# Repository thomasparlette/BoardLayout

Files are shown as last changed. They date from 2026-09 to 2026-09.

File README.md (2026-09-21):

# Grand Marquis 1997 MS3 replacement PCB — R10 eight-layer candidate

> **Engineering checkpoint — not released for fabrication or vehicle use.**

This repository contains the active R10 eight-layer KiCad candidate for a custom controller in a 1997 Mercury Grand Marquis EEC-V enclosure. The design is still `ROUTING_INCOMPLETE`.

## Current verified inventory

The read-only static audit of the native board reports:

- 246 footprints and 888 pads;
- 737 assigned pad/net pairs matching `source/input_netlist.xml`, excluding the intentionally off-board J121 entry;
- eight copper layers (`F.Cu`, `In1.Cu`–`In6.Cu`, `B.Cu`);
- 43,176 segments and 2,230 through vias;
- 102 zero-length segments;
- 207 exact duplicate segment geometries, comprising 208 extra records;
- 3,339 locked segments and 89 locked vias.

Run `py source/production_baseline_audit.py` to regenerate `production_review/BASELINE_AUDIT.md` and the machine-readable audit. This parser is a reproducible inventory tool; it does not replace KiCad DRC, ERC, zone refill, or visual review.

## Stale validation warning

`reports/Routing_validation.json` is behind the current board by 280 segments and four vias. `reports/After_routing_DRC.txt` is also a saved checkpoint, not a current native run. Its 24 unconnected-item findings and other category counts must be regenerated before routing work begins.

## Release blockers

- Native DRC and ERC must be rerun on the current files.
- Every true open, unintended dangling object, zero-length segment, duplicate segment, and unexplained zone island must be resolved without weakening rules.
- The 0.20 mm Default class conflicts with the 0.25 mm signal target in `REQUIREMENTS_CURRENT.md`.
- The eight-layer physical stackup and copper weights are not selected.
- Footprints, procurement BOM, functional pin mapping, current paths, via arrays, thermal interfaces, mechanical fit, and automotive protection remain incompletely qualified.
- Bench, transient, engine, and transmission validation have not been performed.

See `production_review/RELEASE_STATUS.md` and `production_review/KNOWN_HOLDS.md` for the controlling release posture.

## Primary files

- `GrandMarquis97_RevA.kicad_pro`, `.kicad_sch`, and `.kicad_pcb`: active native project.
- `GM97_Layout.pretty`, `GM97.kicad_sym`, and `models`: project libraries.
- `REQUIREMENTS_CURRENT.md`: current project requirements.
- `production_review`: regenerated audit evidence and release status.
- `reports`: current and historical engineering reports; check each report's date and provenance before relying on it.
- `source`: audit and historical routing scripts. Do not rerun historical routing automation wholesale against the active board.

No release Gerbers or drill package are provided.

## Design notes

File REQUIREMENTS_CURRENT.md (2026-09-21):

# 1997 Grand Marquis MS3 EEC-V Replacement Board — Current Requirements

## Vehicle and project objective

- Vehicle: 1997 Mercury Grand Marquis, 4.6 L SOHC 2-valve V8.
- Retain the factory EEC-V PCM enclosure, factory harness connector, mounting arrangement and original case cooling edges.
- Replace the factory PCB with a custom KiCad PCB that hosts the MS3 mainboard interface and an integrated MS3X-equivalent I/O implementation.
- Reuse the verified factory EEC-V connector pad numbering and the supplied Ford pin-reference material.
- Provide design files suitable for a mechanical prototype now and a later manufactured PCB after electrical validation.

## Engine control scope

- Use MegaSquirt 3 architecture with the existing MS3 card.
- Recreate the MS3X functions on the custom PCB.
- Use MapDaddy alone for MAP and barometric pressure.
- Use factory crank and cam signals with appropriate conditioning.
- Retain factory IAC: Ford F6AZ-9F715-EB, 1.0–1.2 A, commanded near 300 Hz.
- Use Bosch OE 62395 high-impedance injectors, 11–18 ohm.
- Initial ignition is dual waste-spark factory coil packs; COP/D585 coils are excluded from this revision.
- Coil primary design target: 4 A RMS per pack, 6 A nominal peak/dwell limit to be verified on the engine.
- Do not include EGR, EVAP, purge or other emissions controls.
- Replace factory narrowband O2 operation with external wideband controllers for Bosch LSU 4.2 or 4.9 sensors.
- Factory O2 heater circuits may provide the external controller supply; narrowband-related wiring may be used as a switched ground/enable only, subject to final schematic verification.

## Transmission and auxiliary control scope

- Retain the 4R70W automatic transmission.
- Use a MicroSquirt v3.0 mounted inside the vehicle for transmission control.
- Add a pass-through connector from the PCM shell to the custom PCB so the MicroSquirt can use the factory harness circuits.
- Pass-through opening available: approximately 0.75 in high by 1.5 in long. A flanged or PCB-edge solution is acceptable; removable crimp terminals are preferred.
- Transmission load assumptions: SSA/SSB 0.4–0.6 A; TCC 0.7–1.2 A; EPC 2.1–4.8 A pulsed. Verify against the actual transmission hardware before release.
- Fuel pump, fan and A/C outputs drive relay coils only. Other auxiliary loads assume 1–1.5 A maximum unless separately specified.

## Electrical requirements

- PCM receives 12 V through the original fused vehicle circuits; upstream ECM fuse is 30 A.
- The board provides internal power regulation.
- Support injector channels and the MS3X I/O assignments supplied by the user, including injector outputs, logic spark outputs, boost/idle mid-current outputs, flex-fuel, launch, table switch, datalog and auxiliary analog inputs.
- Use factory coil driver strategy initially. Requested ignition driver is FGD3245G2-F085C.
- Provide future compatibility for TO-220 and DPAK ignition-driver options, pending pinout, thermal and footprint verification.
- Separate power, digital, sensor and case-ground strategy must be retained and verified with the net-tie implementation.
- Preserve power-path target geometries: 4.0 mm shared VPWR/ACTUATOR_12/PGND target; 3.0 mm coil target; 2.0 mm injector target; 1.2 mm auxiliary/transmission target; 0.6 mm rail target; 0.25 mm signal target. These are design targets, not certified current ratings.

## Mechanical and layout requirements

- Board outline: 140.93 mm × 163.36 mm.
- Nominal board thickness: 1.60 mm.
- Use the supplied factory mounting-hole measurements and actual mounting-hole locations.
- J120, J130, J131 and J140 are located at the bottom/rear of the board.
- Rear cover clearance from the board: 6.35 mm (1/4 in). Components may be mounted on both sides; clearance must be checked.
- Place heat-producing FETs/driver hardware adjacent to the case cooling edges with a defined thermal interface before production.
- Current R10 routing candidate uses eight copper layers: F.Cu, In1–In6.Cu and B.Cu, with through vias only. The final copper weights and dielectric stackup remain to be selected with the fabricator.
- Current underside component moves: D26 (89,120), D27 (80,126), D28 (80,117), D30 (90,131), D33 (78,133), all coordinates in mm.

## Manufacturing and documentation requirements

- Prefer SMD components where feasible; use both sides of the PCB when needed.
- Use JLCPCB constraints for final fabrication rules and confirm the selected eight-layer stackup before release.
- Create/update the BOM with actual orderable Mouser parts and verified footprints.
- Provide KiCad project, schematic sheets, board, custom symbols/footprints/models, BOM, current-routing report, layout images and STL mechanical-fit files.
- Provide a board-only STL and a component-envelope STL for test printing.

## Mandatory completion gates before manufacturing or vehicle use

- Resolve every KiCad unconnected-items error and every clearance, hole-clearance, edge-clearance, courtyard and rule error without suppressing rules.
- Remove unintended track/via dangling stubs and re-run DRC.
- Run a fresh ERC after the schematic is finalized.
- Independently verify the Ford connector pin map and every MS3/MS3X/MicroSquirt connection against authoritative documents and the actual hardware.
- Select and verify every BOM item, especially Q13–Q16 ignition driver footprints/pinouts, pass-through connector, fusing/protection, high-current parts and thermal hardware.
- Select final stackup/copper weights, then verify ampacity, via current sharing, neckdowns and heat dissipation for coils, injectors, IAC, EPC and other loads.
- Complete bench testing with JimStim, dummy loads and the actual MS3/MicroSquirt hardware, followed by automotive transient and engine/transmission validation.
- Confirm the printed mechanical fit in the factory PCM case, including connector engagement, shell pass-through, daughtercard height, MapDaddy/hose clearance, solder/lead protrusion and thermal clips/insulators.

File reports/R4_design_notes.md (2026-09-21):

# Grand Marquis 1997 - R4 engineering review

**NOT FOR FABRICATION, ASSEMBLY OR VEHICLE POWER.** This package contains actual corrected KiCad sources and a routing experiment. It is not a completed or current-qualified ECU. Read the generated reports before use. No Gerbers are supplied.

## Changes

- J101 now follows MS3 JP2 as shown in MS3XV30 Hardware 1.5 pages 205 and 206. In particular Spark A is pin 12, 5 V is pin 31, ground is pins 28/30/32, and 12 V is pins 33/34. The complete reviewed mapping is in reports/JP2_verified_mapping.json.
- Existing MapDaddy alone supplies MAP and barometric pressure. J150 is a four-wire adapter, **not** a native sensor footprint: 1 MAP signal, 2 signal ground, 3 regulated sensor 5 V, 4 barometric signal. Barometric conditioning reaches J100 pin 29 (JS5/AD6). J131 pin 2 is disconnected so an external source cannot drive this dedicated input. Confirm the actual module calibration and wire identities before connecting it.
- Schematic connection geometry aligned to 1.27 mm. Explicit source declarations added for externally supplied/return and derived rails. These flags describe intent; they do not supply power.
- All previous copper removed before synchronization to avoid retaining wrong-header connections. Forty-three small analog components moved to B.Cu. Underside clearance is unmeasured.
- J120/J130/J131/J140 retain the R3 rear-edge positions. Board outline and seven mounting locations retain R3 geometry and its unverified assumptions.
- Factory IAC retained with PWM low-side control. Factory wasted spark uses four power stages; no COP, EGR, purge or EVAP added. External wideband controllers and cabin MicroSquirt remain the intended architecture.

## Current targets are not validated ratings

Routing targets assume 70 micrometres copper and use 2.0 mm injector trunks, 1.2 mm auxiliary trunks, 3.0 mm ignition trunks and 4.0 mm shared power trunks. Signal traces use 0.25 mm. These dimensions alone DO NOT establish current capacity. The proposed copper assumption is not a released stackup.

The user's MS3X table describes the commercial MS3X external DB37, not the internal JP2 connector and not a simultaneous load rating. This PCB uses the Ford connector. Power returns, pad escapes, barrel plating, parallel-via transitions, voltage drop and total load still require assessment. The routing experiment can contain single-via transitions and incomplete paths; it is not suitable for high-current testing.

VND5N07TR-E has a typical 5 A current limit. That is not a guaranteed continuous 5 A channel rating. At 0.2 ohm, 5 A implies 5 W conduction loss per driver before temperature effects; eight such channels cannot be assumed thermally acceptable. No heatsink contact or copper area is qualified by these files.

MK-CoilDrvr is the proposed DIYAutoTune sourcing exception for Q13-Q16. Its exact supplied transistor and physical pinout must be checked against the existing provisional TO-220 footprints. Do not assume BIP373 protection or dwell limits carry over to the replacement device. Ignition primary peak current is separate from the table's 30 mA logic-output rating.

## Validation and remaining work

See reports/Schematic_checks.json and reports/Routing_validation.json. Native KiCad netlist export and PCB DRC were available. Native ERC was not run: this KiCad 7 CLI does not expose ERC. Run Inspect > Electrical Rules Checker in KiCad on the ROOT schematic; keep checks enabled. The custom grid/netlist checks are not equivalent to ERC.

Parts_list.md / reports/Parts_list.json enumerate all schematic components. **This is not an order-ready Mouser BOM.** Unselected components, exact land-pattern compatibility, fuse/PTC coordination, LM2937 load/ESR stability, automotive transients, driver thermal design and the transmission pass-through connector remain holds. No substitute component selection is implied by a generic value.

Further release requirements: finish missing routes; resolve DRC findings; verify ERC; establish stackup and current/thermal budget; verify case fit including module heights, pads and insulators; identify MK-CoilDrvr device; qualify vehicle wiring; complete an actual BOM; bench-test with current-limited power and simulated loads before engine use. This package does not include a validated ECU calibration.

The source migration scripts are one-time transformations of the prior revision, not an idempotent build system. Do not rerun them on this output. route_input.dsn and route_final.ses describe only this routing trial. The native PCB is the review output.

## References

- https://www.msextra.com/doc/pdf/MS3XV30_Hardware-1.5.pdf
- https://www.st.com/resource/en/datasheet/vnd5n07-e.pdf
- https://diyautotune.com/products/mapdaddy4
- https://diyautotune.com/products/mk-coildrvr
- https://www.ti.com/lit/gpn/LM2937

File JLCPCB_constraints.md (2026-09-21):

# JLCPCB fabrication review - 14 September 2026

Manufacturer changed to JLCPCB at the user's request. Reference: https://jlcpcb.com/capabilities/pcb-capabilities

The published multilayer 2 oz track/space minimum is 0.15/0.15 mm. R6 default low-current signal routing uses 0.20/0.20 mm, with some existing 0.25 mm traces retained. Wider load and rail classes retain their targets. JLCPCB lists a 0.254 mm or greater PTH annular ring for 2 oz. The Q1/Q2 draft footprints have only 0.15 mm rings and therefore need revision before a 2 oz release. Increasing the pad diameter alone conflicts with their present pitch.

The page distinguishes via and component-hole rules. Existing vias are 0.8 mm diameter with 0.4 mm drills. The inner copper default is 0.5 oz; do not assume that selecting 2 oz outer copper makes the inner layers 2 oz. Explicit stackup selection and confirmation remain required.

The routing calculations currently assume 70 um copper. This is a proposed build assumption, not a released JLCPCB stackup. Do not order using defaults. Hole plating, copper tolerances, soldermask, legend and the final outline also need fabrication checks.

Factory mounting geometry is retained. JLCPCB manufacturability does not establish the electrical spacing needed around ignition switching nodes, temperature rise, automotive transient immunity, or component compatibility. Those remain separate engineering requirements.

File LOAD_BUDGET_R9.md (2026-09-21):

# R9 routing load basis — provisional

- Four wasted-spark primary channels. User target: 6 A peak operating current, to be measured on the bench. Earlier 4 A RMS applies per coil pack, not each primary. Keep 10 A transient routing allowance per primary until characterized. This PCB does not establish or enforce a 6 A current limit by itself.
- Bosch OE 62395 high-impedance injectors, 11–18 ohms. Published MS3X 5 A channel specification is a reference rating, not proof that the replacement copper or selected devices meet it.
- Factory F6AZ-9F715-EB IAC: 1.0–1.2 A, user-specified 300 Hz PWM.
- External MicroSquirt V3 controls 4R70W. SSA/SSB 0.4–0.6 A; TCC 0.7–1.2 A. EPC 2.1–4.8 A supplied as a resistance-derived range, not a verified RMS waveform. Pass-through contacts and shared return paths require combined-load qualification.
- Remaining unspecified outputs: 1.5 A maximum each. Fuel pump, fan and A/C outputs drive relay coils only.
- ECU input uses factory 30 A upstream fuse. This is not a rating for each PCB trace or a substitute for coordinated board protection.
- Wideband controllers have external power; old heater outputs switch relay/enable loads. MapDaddy supplies MAP and barometric signals.

Trace widths and via arrays are provisional. Final copper weights, temperature rise, duty cycles, driver losses, connector ratings and case thermal interfaces require review before manufacture. The six-layer option preserves the mechanical test-board dimensions and component placements; actual manufacturer stackup is not selected.

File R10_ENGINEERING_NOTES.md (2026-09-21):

# R10 eight-layer routing candidate

Routing is in progress. The latest native result is reports/Routing_validation.json; this document does not declare completion or manufacturing release.

The candidate retains the 140.93 × 163.36 mm outline, mounting-hole coordinates and nominal 1.6 mm board thickness. The following diodes moved to the underside: D26 (89,120), D27 (80,126), D28 (80,117), D30 (90,131), and D33 (78,133), coordinates in millimetres. Other placements are unchanged from R9. Copper layers are F.Cu, In1–In6.Cu and B.Cu. The two added internal layers carry PGND and DGND pours as well as routed traces. Through vias only.

Power routing preserves the unqualified targets in reports/Routing_targets.json. The VPWR branch serving only F1 pin 1 uses a 1.0 mm trunk and 0.6 mm neck; the schematic specifies F1 as 1 A, with its actual part unselected. The ACTUATOR_12 branch serving D33 pin 1 uses the 1.2 mm EPC branch target. Shared VPWR and ACTUATOR_12 trunks remain 4.0 mm targets. Connector fanouts use parallel 0.6 mm necks on three layers and via arrays where space permits. None of these geometries establishes a current rating.

The source-netlist comparison verifies 737 pad/net assignments. This is consistency with the existing design, not an independent verification against Ford and MS3 hardware documentation.

## Release holds

- 216 of 240 parts-list entries remain UNSELECTED; component selection is incomplete.
- Q13–Q16 ignition footprints/pinouts remain on hold. The requested TO-220/DPAK alternatives are not qualified.
- The eight-layer copper weights and dielectric stackup require selection. The 70 µm assumption used for earlier width targets is not a confirmed manufacturing stackup.
- Neckdowns, via arrays, current sharing, coil dwell and thermal interfaces require electrical/thermal validation. A 6 A peak target is not hardware current regulation.
- No fresh schematic ERC is available from this runtime. Historical ERC is not a current pass.
- No bench, dummy-load, automotive-transient or engine/transmission validation has been performed.

## Mechanical fit files

The R10 STL files contain the board and available component body envelopes. The maximum modeled underside depth is 2.22 mm, within the user-specified 6.35 mm cover gap. They exclude solder and leads, the complete MS3 daughtercard, MapDaddy assembly and hoses, cable mating/latch envelopes, Ford connector body/bent-pin envelope, thermal clips and insulating pads. They are fit aids, not a complete assembly-clearance approval.

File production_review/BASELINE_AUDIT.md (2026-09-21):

# R10 static baseline audit

This report inventories the current working-tree native files without modifying the board. The preserved baseline is commit `b5af19f6b018b43a92e55f4675a8856e3b85c9b5`. This audit supplements, but does not replace, native KiCad DRC/ERC. KiCad was not available in the audit environment, so the checked-in DRC remains stale and release-blocking.

## Native-file inventory

- Board format version: `20221018`
- Board thickness: 1.60 mm
- Copper layers: F.Cu, In1.Cu, In2.Cu, In3.Cu, In4.Cu, In5.Cu, In6.Cu, B.Cu
- Embedded physical stackup: **no**
- Footprints / pads / named nets: 246 / 888 / 189
- Segments / vias / zones: 43176 / 2230 / 17
- Locked segments / vias: 3339 / 89
- Zero-length segments: 102
- Exact duplicate segment groups / extra records: 207 / 208
- Exact duplicate via groups / extra records: 0 / 0
- Stored-netlist comparison: 737 assigned pairs, MATCH

## Stale checked-in evidence

`reports/Routing_validation.json` understates the native board by **280 segments** and **4 vias**. The saved DRC was created on 2026-09-14 22:43:03 and was not rerun for this audit.

Saved DRC categories: `{"lib_footprint_mismatch": 199, "silk_edge_clearance": 2, "track_dangling": 199, "unconnected_items": 24, "via_dangling": 15}`

## Rule concerns

- Project minimum track width: 0.0 mm
- Project minimum clearance: 0.0 mm
- Globally ignored categories: footprint_type_mismatch, missing_courtyard, npth_inside_courtyard, pth_inside_courtyard
- DRC exclusions: 0
- The Default class remains 0.20 mm and there is no assigned 0.25 mm Signal class.

## Release disposition

`ROUTING_INCOMPLETE`

Do not modify routing or release fabrication outputs from this static audit. A fresh native DRC and ERC, zone refill, visual review, and all documented electrical/mechanical qualification gates remain required.

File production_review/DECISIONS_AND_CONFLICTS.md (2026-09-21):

# R10 decisions and conflicts

## Baseline preservation

The repository's initial commit, `b5af19f6b018b43a92e55f4675a8856e3b85c9b5`, is the immutable supplied baseline. `baseline/SHA256SUMS.txt` hashes every tracked baseline file. A second in-repository copy of the complete project was intentionally not added because Git already preserves the byte-identical baseline and duplicating the 26 MB board would increase review and repository cost without adding recoverability.

## Stale report conflict

The native board text controls object inventory over `reports/Routing_validation.json`. The board contains 43,176 segments and 2,230 vias; the report contains 42,896 and 2,226. The report is therefore historical until regenerated by native KiCad.

## Signal-width conflict

`REQUIREMENTS_CURRENT.md` and `reports/Routing_targets.json` specify a 0.25 mm signal target. The project Default net class remains 0.20 mm and has no dedicated Signal-class assignment. The 0.25 mm requirement controls unless an engineering decision explicitly changes it. No mass width change is authorized before native DRC and route-by-route review.

## Static versus native validation

The standard-library audit is accepted only for file inventory, exact-geometry checks, saved-report comparison, and stored-netlist mapping. Native KiCad remains controlling for connectivity, zone fill, DRC, ERC, library comparison, and manufacturing plots.

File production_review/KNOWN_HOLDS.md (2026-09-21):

# Known R10 holds

| Hold | Why it matters | Evidence required to close | Blocks |
|---|---|---|---|
| `NATIVE_DRC_HOLD` | Saved counts do not describe the current board. | Fresh native zone refill and DRC with disposition of every finding. | Routing completion and all release states above it |
| `ERC_NOT_RUN` | Logical and power-pin errors may remain in the current schematic hierarchy. | Fresh native ERC and reviewed disposition. | Prototype fabrication |
| `SIGNAL_WIDTH_CONFLICT` | The Default class is 0.20 mm while current requirements specify 0.25 mm signals. | Enforceable class assignment or an approved, documented engineering decision with exceptions. | CAD review |
| `STACKUP_HOLD` | Copper thickness, dielectric geometry, via capability, and impedance/current assumptions are not fixed. | Fabricator-specific eight-layer stackup checked against the design. | Prototype fabrication |
| `PIN_MAPPING_HOLD` | Stored-netlist agreement is not independent functional verification. | Authoritative Ford/MS3/MS3X/MicroSquirt mapping with reviewer sign-off. | Prototype fabrication |
| `IGNITION_DRIVER_HOLD` | Q13–Q16 device, pinout, tab, drive, clamp, package, and case interface are not fully qualified. | Authoritative part data, footprint comparison, electrical review, and thermal/mechanical definition. | Prototype fabrication and vehicle use |
| `BOM_HOLD` | Most exact orderable components and alternates remain unselected. | Buildable, lifecycle-checked BOM with verified footprints. | Prototype fabrication |
| `POWER_THERMAL_HOLD` | Trace targets alone do not establish ampacity or safe temperatures. | End-to-end path, via-sharing, transient, and thermal analyses using the selected stackup and real loads. | Prototype fabrication |
| `MECHANICAL_HOLD` | Existing models omit critical bodies, leads, connectors, hoses, daughtercard, and thermal hardware. | Complete envelope model, test print, and actual enclosure fit check. | Prototype fabrication |
| `PHYSICAL_TEST_HOLD` | No prototype, dummy-load, transient, thermal, or vehicle evidence is archived. | Controlled test results and corrective-action closure. | Production release and vehicle validation |

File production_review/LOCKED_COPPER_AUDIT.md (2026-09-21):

# Locked copper audit summary

The native board contains **3339 locked segments** and **89 locked vias**. `LOCKED_COPPER_AUDIT.csv` groups them by net and layer/span. This is an inventory only: route purpose and justification still require engineering review before any lock is removed.

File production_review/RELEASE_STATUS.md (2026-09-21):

# R10 release status

## Current state

`ROUTING_INCOMPLETE`

The current static baseline confirms that the saved validation reports are stale and that copper cleanup and true electrical connections remain unresolved. No fabrication package is authorized.

## Evidence available

- Native-board static inventory in `BASELINE_AUDIT.md` and `BASELINE_AUDIT.json`.
- 737 assigned PCB pad/net pairs match the stored source netlist, excluding J121.
- Checked-in saved DRC from 2026-09-14, retained only as a checkpoint.
- Existing mechanical envelope models retained as fit aids, not physical qualification.

## Evidence still required

- Fresh native KiCad board load, zone refill, DRC, and schematic ERC.
- Reviewed routing repairs and copper cleanup with before/after evidence.
- Independent Ford/MS3/MS3X/MicroSquirt functional mapping.
- Selected and verified footprints, BOM, stackup, copper weights, current paths, vias, and thermal interfaces.
- Complete mechanical fit evidence and prototype fabrication outputs.
- Prototype assembly, bench, automotive-transient, thermal, and vehicle testing as applicable to each higher release state.

The state must not advance until the applicable evidence exists in the repository and has been reviewed.

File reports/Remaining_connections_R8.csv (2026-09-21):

finding | x1_mm | y1_mm | item1 | x2_mm | y2_mm | item2
1 | 53.2000 | 65.7000 | Via [ACTUATOR_12] on F.Cu - B.Cu | 30.4000 | 46.9000 | Track [ACTUATOR_12] on In2.Cu, length 0.4243 mm
2 | 36.2000 | 35.9000 | Track [ACTUATOR_12] on F.Cu, length 0.0566 mm | 82.1700 | 27.9480 | Track [ACTUATOR_12] on F.Cu, length 0.0566 mm
3 | 90.5650 | 5.3000 | PTH pad 69 [AC_WOT_CUTOUT] of J1 | 47.8000 | 122.4000 | Track [AC_WOT_CUTOUT] on B.Cu, length 0.8485 mm
4 | 110.9000 | 138.3000 | Track [CKP_PLUS] on F.Cu, length 0.1000 mm | 104.1650 | 11.2000 | PTH pad 21 [CKP_PLUS] of J1
5 | 77.4000 | 21.7000 | Track [COIL_2] on B.Cu, length 0.8485 mm | 40.6000 | 44.0000 | Track [COIL_2] on In2.Cu, length 0.8485 mm
6 | 34.8750 | 150.7180 | PTH pad 2 [COIL_3] of Q15 | 121.1650 | 5.3000 | PTH pad 78 [COIL_3] of J1
7 | 102.2000 | 39.4000 | Track [COIL_4] on B.Cu, length 0.8485 mm | 109.7000 | 29.7000 | Track [COIL_4] on In2.Cu, length 1.8000 mm
8 | 106.7000 | 143.9000 | Track [DGND] on B.Cu, length 0.2000 mm | 107.6000 | 143.0000 | Track [DGND] on In1.Cu, length 1.2728 mm
9 | 99.0650 | 8.2500 | PTH pad 45 [FAN_CONTROL] of J1 | 25.9500 | 110.6050 | Track [FAN_CONTROL] on F.Cu, length 3.0500 mm
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

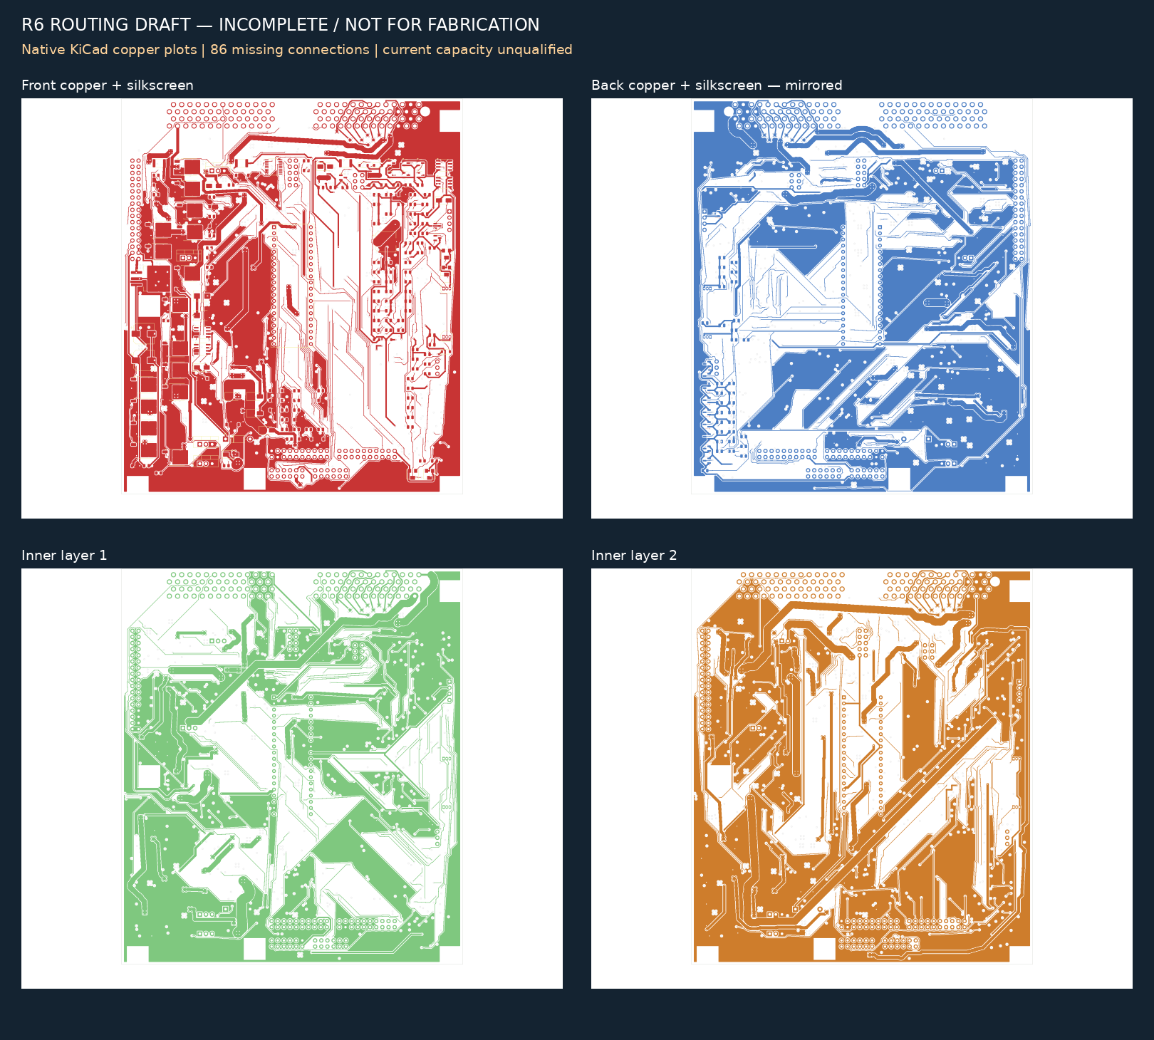
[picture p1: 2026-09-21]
mechanical/Layout_R6.png

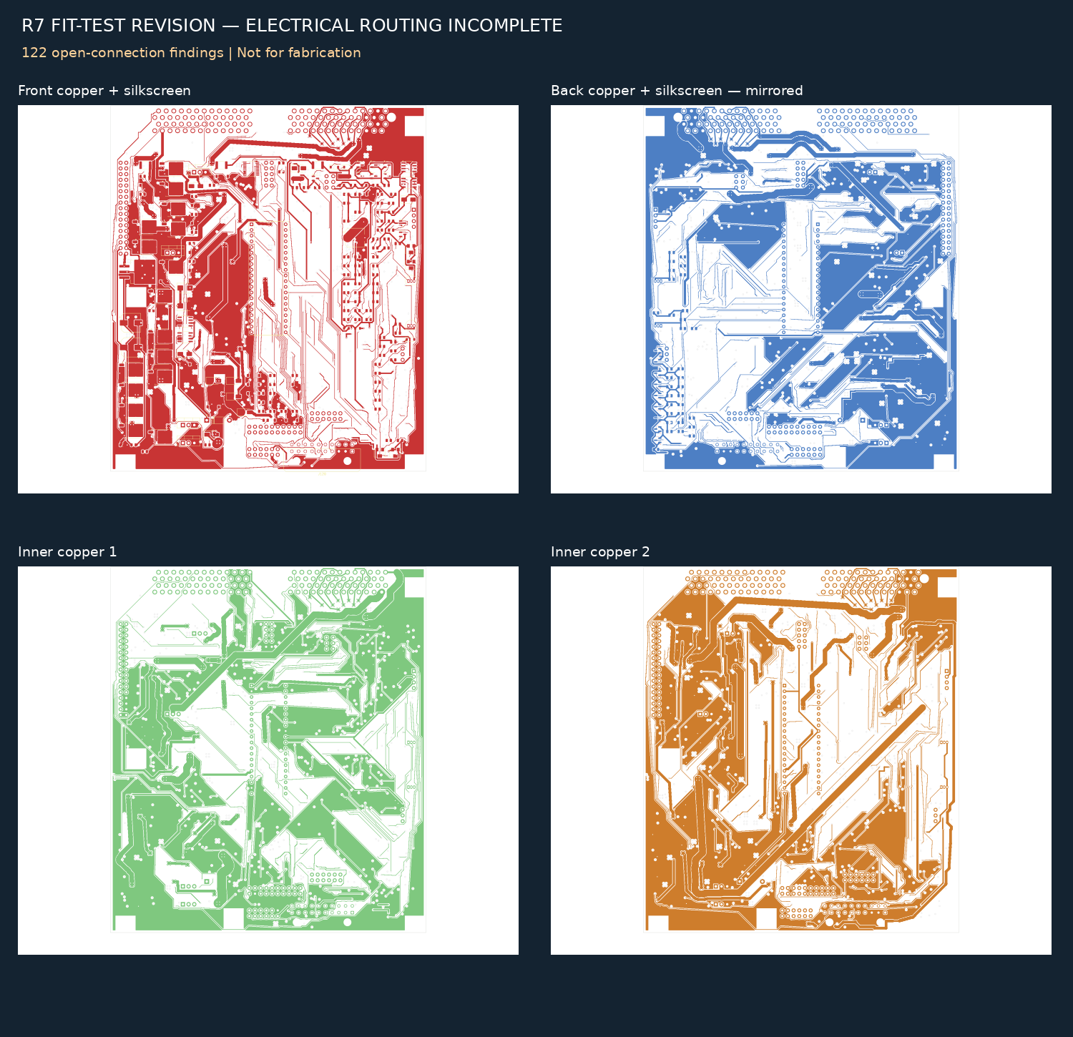
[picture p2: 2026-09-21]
mechanical/Layout_R7.png

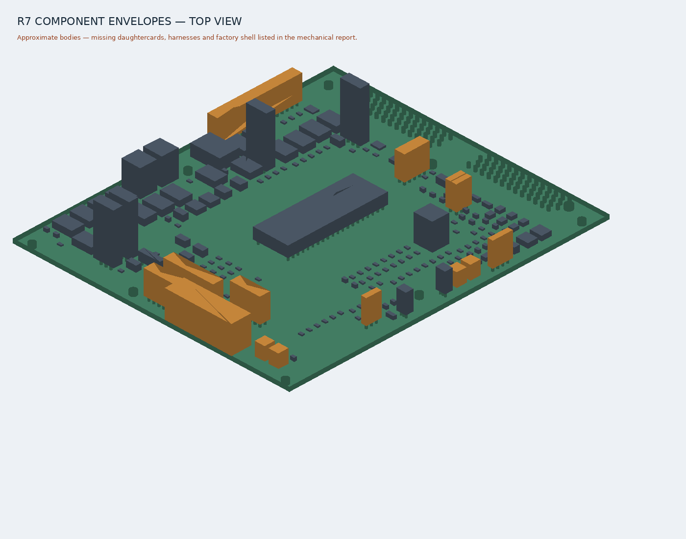
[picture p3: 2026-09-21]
mechanical/R7_Envelope_Preview.png

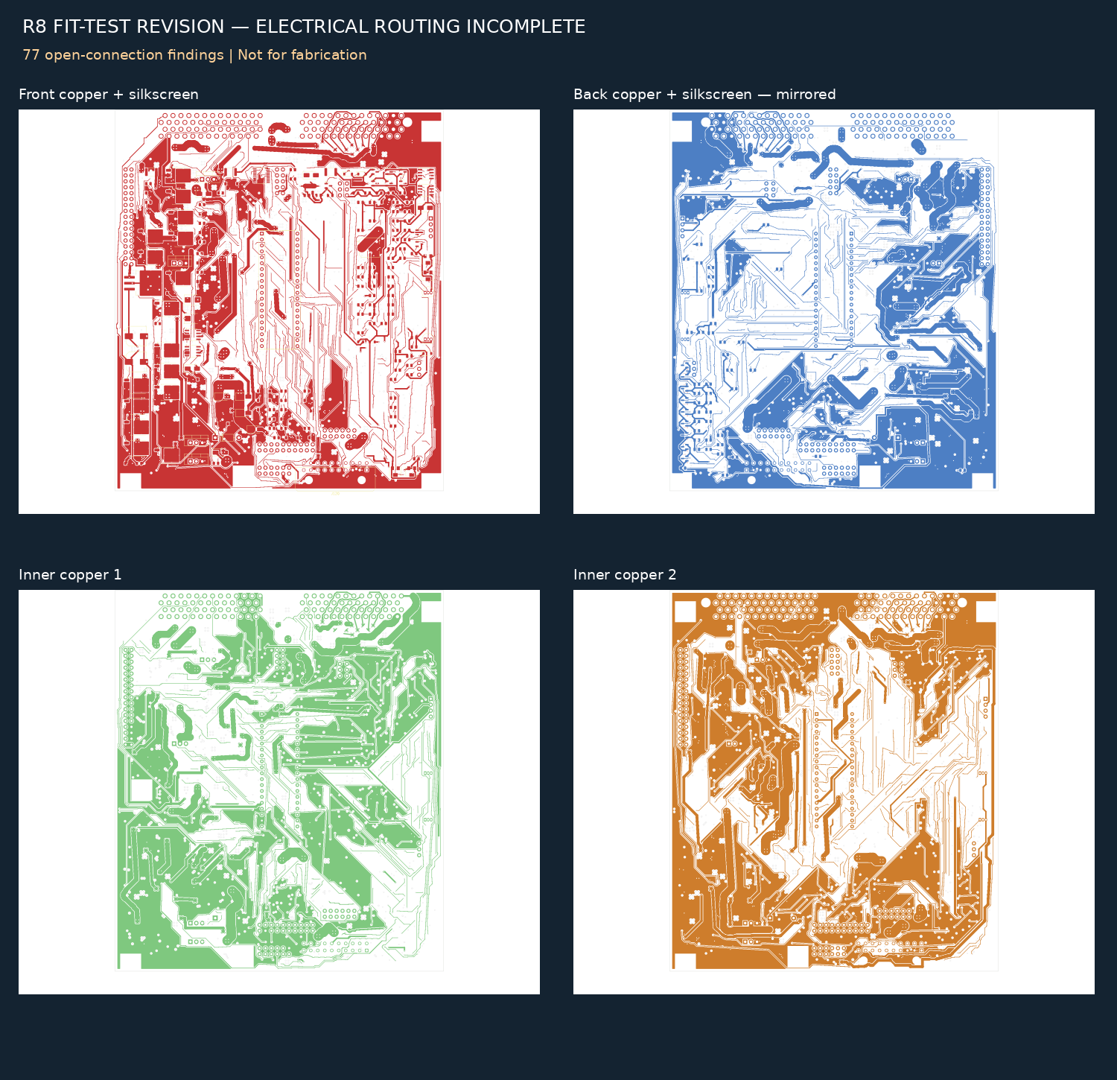
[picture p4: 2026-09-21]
mechanical/Layout_R8.png

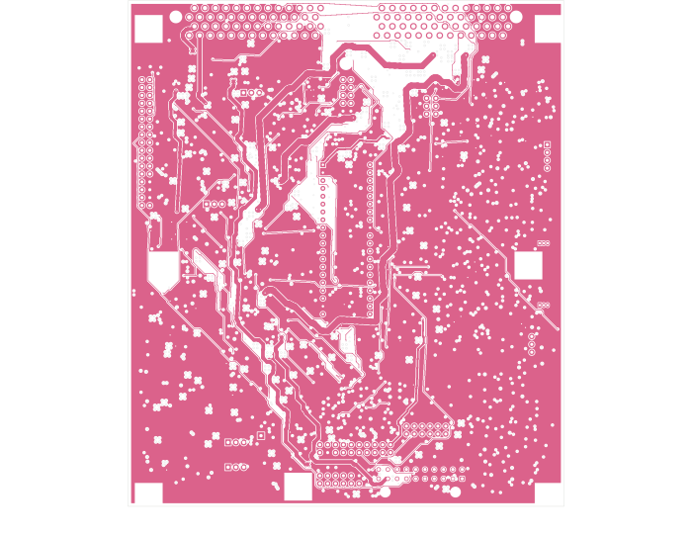
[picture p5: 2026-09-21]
mechanical/inner4.png

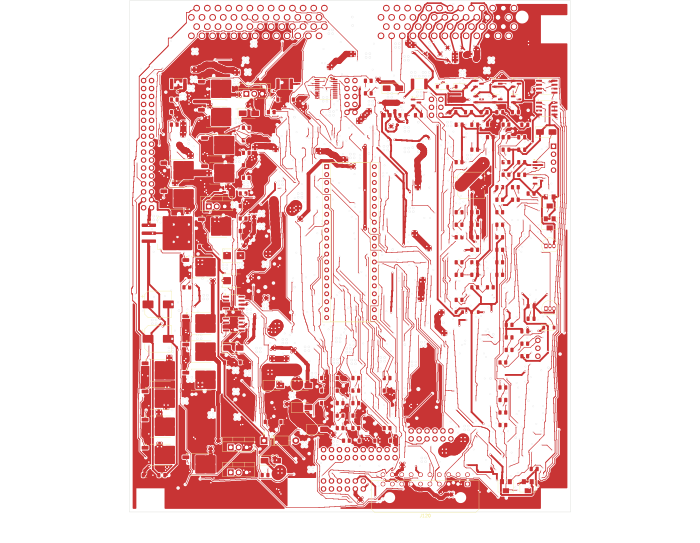
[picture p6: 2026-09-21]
mechanical/top.png

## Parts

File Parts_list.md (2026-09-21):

# R7 parts inventory — engineering review only

Not an order-ready BOM. All UNSELECTED entries and electrical/thermal limits remain open.

| Reference | Value | Part | Status |
|---|---|---|---|
| C1 | 33 uF / 50 V | UNSELECTED | HOLD: exact part and footprint qualification incomplete |
| C2 | 100 nF / 100 V | UNSELECTED | HOLD: exact part and footprint qualification incomplete |
| C3 | 33 uF / 10 V | UNSELECTED | HOLD: exact part and footprint qualification incomplete |
| C4 | 100 nF | UNSELECTED | HOLD: exact part and footprint qualification incomplete |
| C5 | 47 uF / 10 V | UNSELECTED | HOLD: exact part and footprint qualification incomplete |
| D1 | STPS3H100 | UNSELECTED | HOLD: exact part and footprint qualification incomplete |
| D2 | SMBJ18A TVS | UNSELECTED | HOLD: exact part and footprint qualification incomplete |
| D3 | 400V 1A SMA / MPN TBD | UNSELECTED | HOLD: exact part and footprint qualification incomplete |
| D4 | 1N4734A 5.6 V | UNSELECTED | HOLD: exact part and footprint qualification incomplete |
| F1 | 1 A SMD fuse / MPN TBD | UNSELECTED | HOLD: exact part and footprint qualification incomplete |
| F2 | PTC 0.5 A | UNSELECTED | HOLD: exact part and footprint qualification incomplete |
| U1 | LM2937ES-5.0 / SMD candidate | LM2937ES-5.0/NOPB | TI/Mouser candidate; load budget and output capacitor ESR/thermal HOLD |
| C6 | 4.7 uF | UNSELECTED | HOLD: exact part and footprint qualification incomplete |
| C7 | 100 nF | UNSELECTED | HOLD: exact part and footprint qualification incomplete |
| C8 | 4.7 uF | UNSELECTED | HOLD: exact part and footprint qualification incomplete |
| C9 | 100 nF | UNSELECTED | HOLD: exact part and footprint qualification incomplete |
| F3 | PTC 0.1 A | UNSELECTED | HOLD: exact part and footprint qualification incomplete |
| L1 | 1 uH | UNSELECTED | HOLD: exact part and footprint qualification incomplete |
| L2 | 1 uH | UNSELECTED | HOLD: exact part and footprint qualification incomplete |
| NT1 | NET_TIE | UNSELECTED | HOLD: exact part and footprint qualification incomplete |
| NT2 | NET_TIE | UNSELECTED | HOLD: exact part and footprint qualification incomplete |
| R1 | 0R DNP | UNSELECTED | HOLD: exact part and footprint qualification incomplete |
| R2 | 120R DNP | UNSELECTED | HOLD: exact part and footprint qualification incomplete |
| C10 | 100 nF | UNSELECTED | HOLD: exact part and footprint qualification incomplete |
| J100 | MS3_40_SOCKET | UNSELECTED | HOLD: exact part and footprint qualification incomplete |
| J101 | MS3_JP2_34 | UNSELECTED | HOLD: exact part and footprint qualification incomplete |
| J102 | MS3_INJ_10 | UNSELECTED | HOLD: exact part and footprint qualification incomplete |
| J1 | Ford104 | Salvaged original Ford 104-pin header | User accepted cavity mapping; contact ratings and mounting qualification HOLD |
| C11 | 1 uF | UNSELECTED | HOLD: exact part and footprint qualification incomplete |
| C12 | 1 nF | UNSELECTED | HOLD: exact part and footprint qualification incomplete |
| C13 | 1 uF | UNSELECTED | HOLD: exact part and footprint qualification incomplete |
| C14 | 1 nF | UNSELECTED | HOLD: exact part and footprint qualification incomplete |
| C15 | 220 nF | UNSELECTED | HOLD: exact part and footprint qualification incomplete |
| C16 | 1 nF | UNSELECTED | HOLD: exact part and footprint qualification incomplete |
| C17 | 220 nF | UNSELECTED | HOLD: exact part and footprint qualification incomplete |
| C18 | 1 nF | UNSELECTED | HOLD: exact part and footprint qualification incomplete |
| D5 | BAT54S | UNSELECTED | HOLD: exact part and footprint qualification incomplete |
| D6 | BAT54S | UNSELECTED | HOLD: exact part and footprint qualification incomplete |
| D7 | BAT54S | UNSELECTED | HOLD: exact part and footprint qualification incomplete |
| D8 | BAT54S | UNSELECTED | HOLD: exact part and footprint qualification incomplete |
| R3 | 2.2k | UNSELECTED | HOLD: exact part and footprint qualification incomplete |
| R4 | 2.49k 1% | UNSELECTED | HOLD: exact part and footprint qualification incomplete |
| R5 | 2.2k | UNSELECTED | HOLD: exact part and footprint qualification incomplete |
| R6 | 2.49k 1% | UNSELECTED | HOLD: exact part and footprint qualification incomplete |
| R7 | 1k | UNSELECTED | HOLD: exact part and footprint qualification incomplete |
| R8 | 1M | UNSELECTED | HOLD: exact part and footprint qualification incomplete |
| R9 | 1k | UNSELECTED | HOLD: exact part and footprint qualification incomplete |
| R10 | 1M | UNSELECTED | HOLD: exact part and footprint qualification incomplete |
| C19 | 220 nF | UNSELECTED | HOLD: exact part and footprint qualification incomplete |
| C20 | 1 nF | UNSELECTED | HOLD: exact part and footprint qualification incomplete |
| C21 | 220 nF | UNSELECTED | HOLD: exact part and footprint qualification incomplete |
| C22 | 1 nF | UNSELECTED | HOLD: exact part and footprint qualification incomplete |
| C23 | 220 nF | UNSELECTED | HOLD: exact part and footprint qualification incomplete |
| C24 | 1 nF | UNSELECTED | HOLD: exact part and footprint qualification incomplete |
| C25 | 220 nF | UNSELECTED | HOLD: exact part and footprint qualification incomplete |
| C26 | 1 nF | UNSELECTED | HOLD: exact part and footprint qualification incomplete |
| D9 | BAT54S | UNSELECTED | HOLD: exact part and footprint qualification incomplete |
| D10 | BAT54S | UNSELECTED | HOLD: exact part and footprint qualification incomplete |
| D11 | BAT54S | UNSELECTED | HOLD: exact part and footprint qualification incomplete |
| D12 | BAT54S | UNSELECTED | HOLD: exact part and footprint qualification incomplete |
| R11 | 1k | UNSELECTED | HOLD: exact part and footprint qualification incomplete |
| R12 | 1M | UNSELECTED | HOLD: exact part and footprint qualification incomplete |
| R13 | 1k | UNSELECTED | HOLD: exact part and footprint qualification incomplete |
| R14 | 1M | UNSELECTED | HOLD: exact part and footprint qualification incomplete |
| R15 | 1k | UNSELECTED | HOLD: exact part and footprint qualification incomplete |
| R16 | 1M | UNSELECTED | HOLD: exact part and footprint qualification incomplete |
| R17 | 1k | UNSELECTED | HOLD: exact part and footprint qualification incomplete |
| R18 | 1M | UNSELECTED | HOLD: exact part and footprint qualification incomplete |
| C27 | 220 nF | UNSELECTED | HOLD: exact part and footprint qualification incomplete |
| C28 | 100 nF | UNSELECTED | HOLD: exact part and footprint qualification incomplete |
| C29 | 100 nF | UNSELECTED | HOLD: exact part and footprint qualification incomplete |
| C30 | 220 nF | UNSELECTED | HOLD: exact part and footprint qualification incomplete |
| D13 | BAT54S | UNSELECTED | HOLD: exact part and footprint qualification incomplete |
| D14 | BAT54S | UNSELECTED | HOLD: exact part and footprint qualification incomplete |
| J150 | MapDaddy wired interface - user supplied module | 4-position wired adapter | Custom pin order; NOT a native MapDaddy package footprint; mount dimensions HOLD |
| R19 | 1k | UNSELECTED | HOLD: exact part and footprint qualification incomplete |
| R20 | 50k 1% | UNSELECTED | HOLD: exact part and footprint qualification incomplete |
| R21 | 10k 1% | UNSELECTED | HOLD: exact part and footprint qualification incomplete |
| R22 | 1k | UNSELECTED | HOLD: exact part and footprint qualification incomplete |
| R23 | 1M | UNSELECTED | HOLD: exact part and footprint qualification incomplete |
| C31 | 1 nF | UNSELECTED | HOLD: exact part and footprint qualification incomplete |
| C32 | 1 nF DNP | UNSELECTED | HOLD: exact part and footprint qualification incomplete |
| C33 | 100 nF | UNSELECTED | HOLD: exact part and footprint qualification incomplete |
| D15 | 1N4148W / candidate | UNSELECTED | HOLD: exact part and footprint qualification incomplete |
| Q1 | ZTX553 | UNSELECTED | HOLD: exact part and footprint qualification incomplete |
| Q2 | ZTX553 | UNSELECTED | HOLD: exact part and footprint qualification incomplete |
| R24 | 10k | UNSELECTED | HOLD: exact part and footprint qualification incomplete |
| R25 | 10k | UNSELECTED | HOLD: exact part and footprint qualification incomplete |
| R26 | 1M | UNSELECTED | HOLD: exact part and footprint qualification incomplete |
| R27 | 47k | UNSELECTED | HOLD: exact part and footprint qualification incomplete |
| R28 | 10k | UNSELECTED | HOLD: exact part and footprint qualification incomplete |
| R29 | 10k | UNSELECTED | HOLD: exact part and footprint qualification incomplete |
| R30 | 10k | UNSELECTED | HOLD: exact part and footprint qualification incomplete |
| R31 | 10k | UNSELECTED | HOLD: exact part and footprint qualification incomplete |
| R32 | 1k | UNSELECTED | HOLD: exact part and footprint qualification incomplete |
| R33 | 1k | UNSELECTED | HOLD: exact part and footprint qualification incomplete |
| R34 | 100k | UNSELECTED | HOLD: exact part and footprint qualification incomplete |
| R35 | 100k | UNSELECTED | HOLD: exact part and footprint qualification incomplete |
| R36 | 0R | UNSELECTED | HOLD: exact part and footprint qualification incomplete |
| U3 | MC34072 SOIC / candidate | UNSELECTED | HOLD: exact part and footprint qualification incomplete |
| C34 | 220 nF | UNSELECTED | HOLD: exact part and footprint qualification incomplete |
| C35 | 1 nF | UNSELECTED | HOLD: exact part and footprint qualification incomplete |
| D16 | 400V 1A SMA / MPN TBD | UNSELECTED | HOLD: exact part and footprint qualification incomplete |
| JP1 | CRANK POLARITY | UNSELECTED | HOLD: exact part and footprint qualification incomplete |
| R37 | 1k | UNSELECTED | HOLD: exact part and footprint qualification incomplete |
| R38 | 1k | UNSELECTED | HOLD: exact part and footprint qualification incomplete |
| R39 | 1M | UNSELECTED | HOLD: exact part and footprint qualification incomplete |
| R40 | 47k | UNSELECTED | HOLD: exact part and footprint qualification incomplete |
| R41 | 100k | UNSELECTED | HOLD: exact part and footprint qualification incomplete |
| R42 | 1k | UNSELECTED | HOLD: exact part and footprint qualification incomplete |
| R43 | 100k | UNSELECTED | HOLD: exact part and footprint qualification incomplete |
| R44 | 1k | UNSELECTED | HOLD: exact part and footprint qualification incomplete |
| R45 | 2.2k DNP | UNSELECTED | HOLD: exact part and footprint qualification incomplete |
| RV1 | 10k / CRANK ZERO | UNSELECTED | HOLD: exact part and footprint qualification incomplete |
| RV2 | 100k / CRANK HYST | UNSELECTED | HOLD: exact part and footprint qualification incomplete |
| C36 | 100 nF | UNSELECTED | HOLD: exact part and footprint qualification incomplete |
| Q3 | MMBT2907A | UNSELECTED | HOLD: exact part and footprint qualification incomplete |
| Q4 | MMBT2907A | UNSELECTED | HOLD: exact part and footprint qualification incomplete |
| RV3 | 10k / CAM ZERO | UNSELECTED | HOLD: exact part and footprint qualification incomplete |
| RV4 | 100k / CAM HYST | UNSELECTED | HOLD: exact part and footprint qualification incomplete |
| U4 | MCP6002-I/SN | UNSELECTED | HOLD: exact part and footprint qualification incomplete |
| Q5 | VND5N07 | VND5N07TR-E | ST datasheet/order code checked; thermal and current qualification HOLD |
| Q6 | VND5N07 | VND5N07TR-E | ST datasheet/order code checked; thermal and current qualification HOLD |
| Q7 | VND5N07 | VND5N07TR-E | ST datasheet/order code checked; thermal and current qualification HOLD |
| Q8 | VND5N07 | VND5N07TR-E | ST datasheet/order code checked; thermal and current qualification HOLD |
| R46 | 1k | UNSELECTED | HOLD: exact part and footprint qualification incomplete |
| R47 | 100k | UNSELECTED | HOLD: exact part and footprint qualification incomplete |
| R48 | 1k | UNSELECTED | HOLD: exact part and footprint qualification incomplete |
| R49 | 100k | UNSELECTED | HOLD: exact part and footprint qualification incomplete |
| R50 | 1k | UNSELECTED | HOLD: exact part and footprint qualification incomplete |
| R51 | 100k | UNSELECTED | HOLD: exact part and footprint qualification incomplete |
| R52 | 1k | UNSELECTED | HOLD: exact part and footprint qualification incomplete |
| R53 | 100k | UNSELECTED | HOLD: exact part and footprint qualification incomplete |
| Q9 | VND5N07 | VND5N07TR-E | ST datasheet/order code checked; thermal and current qualification HOLD |
| Q10 | VND5N07 | VND5N07TR-E | ST datasheet/order code checked; thermal and current qualification HOLD |
| Q11 | VND5N07 | VND5N07TR-E | ST datasheet/order code checked; thermal and current qualification HOLD |
| Q12 | VND5N07 | VND5N07TR-E | ST datasheet/order code checked; thermal and current qualification HOLD |
| R54 | 1k | UNSELECTED | HOLD: exact part and footprint qualification incomplete |
| R55 | 100k | UNSELECTED | HOLD: exact part and footprint qualification incomplete |
| R56 | 1k | UNSELECTED | HOLD: exact part and footprint qualification incomplete |
| R57 | 100k | UNSELECTED | HOLD: exact part and footprint qualification incomplete |
| R58 | 1k | UNSELECTED | HOLD: exact part and footprint qualification incomplete |
| R59 | 100k | UNSELECTED | HOLD: exact part and footprint qualification incomplete |
| R60 | 1k | UNSELECTED | HOLD: exact part and footprint qualification incomplete |
| R61 | 100k | UNSELECTED | HOLD: exact part and footprint qualification incomplete |
| C37 | 100 nF | UNSELECTED | HOLD: exact part and footprint qualification incomplete |
| R62 | 100k | UNSELECTED | HOLD: exact part and footprint qualification incomplete |
| R64 | 100k | UNSELECTED | HOLD: exact part and footprint qualification incomplete |
| R66 | 100k | UNSELECTED | HOLD: exact part and footprint qualification incomplete |
| R68 | 100k | UNSELECTED | HOLD: exact part and footprint qualification incomplete |
| U5 | SN74AHCT541PWR | UNSELECTED | HOLD: exact part and footprint qualification incomplete |
| C38 | 100 nF | UNSELECTED | HOLD: exact part and footprint qualification incomplete |
| C39 | 100 nF | UNSELECTED | HOLD: exact part and footprint qualification incomplete |
| Q13 | MK-CoilDrvr IGBT - PINOUT HOLD | MK-CoilDrvr | Kit specified; underlying IGBT MPN/pinout and case mounting HOLD |
| Q14 | MK-CoilDrvr IGBT - PINOUT HOLD | MK-CoilDrvr | Kit specified; underlying IGBT MPN/pinout and case mounting HOLD |
| Q15 | MK-CoilDrvr IGBT - PINOUT HOLD | MK-CoilDrvr | Kit specified; underlying IGBT MPN/pinout and case mounting HOLD |
| Q16 | MK-CoilDrvr IGBT - PINOUT HOLD | MK-CoilDrvr | Kit specified; underlying IGBT MPN/pinout and case mounting HOLD |
| R78 | 100k | UNSELECTED | HOLD: exact part and footprint qualification incomplete |
| R79 | 100k | UNSELECTED | HOLD: exact part and footprint qualification incomplete |
| R80 | 100k | UNSELECTED | HOLD: exact part and footprint qualification incomplete |
| R81 | 100k | UNSELECTED | HOLD: exact part and footprint qualification incomplete |
| R82 | 0R | UNSELECTED | HOLD: exact part and footprint qualification incomplete |
| R83 | 330R | UNSELECTED | HOLD: exact part and footprint qualification incomplete |
| R84 | 0R | UNSELECTED | HOLD: exact part and footprint qualification incomplete |
| R85 | 330R | UNSELECTED | HOLD: exact part and footprint qualification incomplete |
| R86 | 0R | UNSELECTED | HOLD: exact part and footprint qualification incomplete |
| R87 | 330R | UNSELECTED | HOLD: exact part and footprint qualification incomplete |
| R88 | 0R | UNSELECTED | HOLD: exact part and footprint qualification incomplete |
| R89 | 330R | UNSELECTED | HOLD: exact part and footprint qualification incomplete |
| U6 | TC4427A | UNSELECTED | HOLD: exact part and footprint qualification incomplete |
| U7 | TC4427A | UNSELECTED | HOLD: exact part and footprint qualification incomplete |
| D17 | 400V 1A SMA / MPN TBD | UNSELECTED | HOLD: exact part and footprint qualification incomplete |
| D18 | 400V 1A SMA / MPN TBD | UNSELECTED | HOLD: exact part and footprint qualification incomplete |
| D19 | 400V 1A SMA / MPN TBD | UNSELECTED | HOLD: exact part and footprint qualification incomplete |
| Q17 | VND5N07 | VND5N07TR-E | ST datasheet/order code checked; thermal and current qualification HOLD |
| Q18 | VND5N07 | VND5N07TR-E | ST datasheet/order code checked; thermal and current qualification HOLD |
| Q19 | VND5N07 | VND5N07TR-E | ST datasheet/order code checked; thermal and current qualification HOLD |
| R90 | 1k | UNSELECTED | HOLD: exact part and footprint qualification incomplete |
| R91 | 100k | UNSELECTED | HOLD: exact part and footprint qualification incomplete |
| R92 | 1k | UNSELECTED | HOLD: exact part and footprint qualification incomplete |
| R93 | 100k | UNSELECTED | HOLD: exact part and footprint qualification incomplete |
| R94 | 1k | UNSELECTED | HOLD: exact part and footprint qualification incomplete |
| R95 | 100k | UNSELECTED | HOLD: exact part and footprint qualification incomplete |
| D22 | 400V 1A SMA / MPN TBD | UNSELECTED | HOLD: exact part and footprint qualification incomplete |
| Q22 | VND5N07 | VND5N07TR-E | ST datasheet/order code checked; thermal and current qualification HOLD |
| R100 | 1k | UNSELECTED | HOLD: exact part and footprint qualification incomplete |
| R101 | 100k | UNSELECTED | HOLD: exact part and footprint qualification incomplete |
| D23 | 400V 1A SMA / MPN TBD | UNSELECTED | HOLD: exact part and footprint qualification incomplete |
| D24 | 400V 1A SMA / MPN TBD | UNSELECTED | HOLD: exact part and footprint qualification incomplete |
| Q23 | VND5N07 | VND5N07TR-E | ST datasheet/order code checked; thermal and current qualification HOLD |
| Q24 | VND5N07 | VND5N07TR-E | ST datasheet/order code checked; thermal and current qualification HOLD |
| R102 | 1k | UNSELECTED | HOLD: exact part and footprint qualification incomplete |
| R103 | 100k | UNSELECTED | HOLD: exact part and footprint qualification incomplete |
| R104 | 1k | UNSELECTED | HOLD: exact part and footprint qualification incomplete |
| R105 | 100k | UNSELECTED | HOLD: exact part and footprint qualification incomplete |
| Q26 | VND5N07 | VND5N07TR-E | ST datasheet/order code checked; thermal and current qualification HOLD |
| Q27 | VND5N07 | VND5N07TR-E | ST datasheet/order code checked; thermal and current qualification HOLD |
| R108 | 1k | UNSELECTED | HOLD: exact part and footprint qualification incomplete |
| R109 | 100k | UNSELECTED | HOLD: exact part and footprint qualification incomplete |
| R110 | 1k | UNSELECTED | HOLD: exact part and footprint qualification incomplete |
| R111 | 100k | UNSELECTED | HOLD: exact part and footprint qualification incomplete |
| C40 | 100 nF | UNSELECTED | HOLD: exact part and footprint qualification incomplete |
| C41 | 100 nF | UNSELECTED | HOLD: exact part and footprint qualification incomplete |
| C42 | 100 nF | UNSELECTED | HOLD: exact part and footprint qualification incomplete |
| C43 | 100 nF | UNSELECTED | HOLD: exact part and footprint qualification incomplete |
| D26 | BAT54S | UNSELECTED | HOLD: exact part and footprint qualification incomplete |
| D27 | BAT54S | UNSELECTED | HOLD: exact part and footprint qualification incomplete |
| D28 | BAT54S | UNSELECTED | HOLD: exact part and footprint qualification incomplete |
| D29 | BAT54S | UNSELECTED | HOLD: exact part and footprint qualification incomplete |
| R116 | 10k | UNSELECTED | HOLD: exact part and footprint qualification incomplete |
| R117 | 2.2k | UNSELECTED | HOLD: exact part and footprint qualification incomplete |
| R118 | 10k | UNSELECTED | HOLD: exact part and footprint qualification incomplete |
| R119 | 2.2k | UNSELECTED | HOLD: exact part and footprint qualification incomplete |
| R120 | 10k | UNSELECTED | HOLD: exact part and footprint qualification incomplete |
| R121 | 2.2k | UNSELECTED | HOLD: exact part and footprint qualification incomplete |
| R122 | 10k | UNSELECTED | HOLD: exact part and footprint qualification incomplete |
| R123 | 2.2k | UNSELECTED | HOLD: exact part and footprint qualification incomplete |
| D30 | 1N4148W / candidate | UNSELECTED | HOLD: exact part and footprint qualification incomplete |
| D31 | 1N4148W / candidate | UNSELECTED | HOLD: exact part and footprint qualification incomplete |
| D32 | BAT54S | UNSELECTED | HOLD: exact part and footprint qualification incomplete |
| Q30 | MMBT3904 | UNSELECTED | HOLD: exact part and footprint qualification incomplete |
| Q31 | MMBT3904 | UNSELECTED | HOLD: exact part and footprint qualification incomplete |
| R124 | 47k | UNSELECTED | HOLD: exact part and footprint qualification incomplete |
| R125 | 100k | UNSELECTED | HOLD: exact part and footprint qualification incomplete |
| R126 | 47k | UNSELECTED | HOLD: exact part and footprint qualification incomplete |
| R127 | 100k | UNSELECTED | HOLD: exact part and footprint qualification incomplete |
| R128 | 0R DNP | UNSELECTED | HOLD: exact part and footprint qualification incomplete |
| R129 | 2.2k | UNSELECTED | HOLD: exact part and footprint qualification incomplete |
| R130 | 10k | UNSELECTED | HOLD: exact part and footprint qualification incomplete |
| D33 | 400V 1A SMA / MPN TBD | UNSELECTED | HOLD: exact part and footprint qualification incomplete |
| J120 | Molex 43045-2000 | 43045-2000 | Selected header; verify mating assembly and simultaneous-current derating |
| JP2 | SPEED SOURCE + | UNSELECTED | HOLD: exact part and footprint qualification incomplete |
| JP3 | SPEED RETURN - | UNSELECTED | HOLD: exact part and footprint qualification incomplete |
| R131 | 2.2k DNP | UNSELECTED | HOLD: exact part and footprint qualification incomplete |
| R132 | 10k DNP | UNSELECTED | HOLD: exact part and footprint qualification incomplete |
| R133 | 2.49k DNP | UNSELECTED | HOLD: exact part and footprint qualification incomplete |
| J130 | SERVICE | UNSELECTED | HOLD: exact part and footprint qualification incomplete |
| J131 | EXPANSION | UNSELECTED | HOLD: exact part and footprint qualification incomplete |
| J140 | RETENTION_12 | UNSELECTED | HOLD: exact part and footprint qualification incomplete |
| J121 | SEALED SHELL FEEDTHROUGH | UNSELECTED | HOLD: exact part and footprint qualification incomplete |

Harness accessories: 43025-2000 housing, 43030-0007 female crimp terminals, 11-03-0043 extraction tool. Contact count and wire sizes must be assigned against the final MicroSquirt harness schedule.

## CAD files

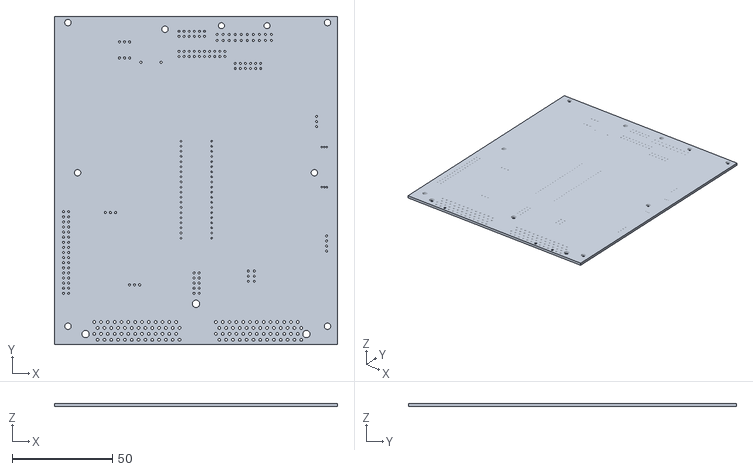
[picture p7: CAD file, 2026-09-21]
mechanical/R10_Bare_Board_1p6mm.stl
140.9 x 163.4 x 1.60

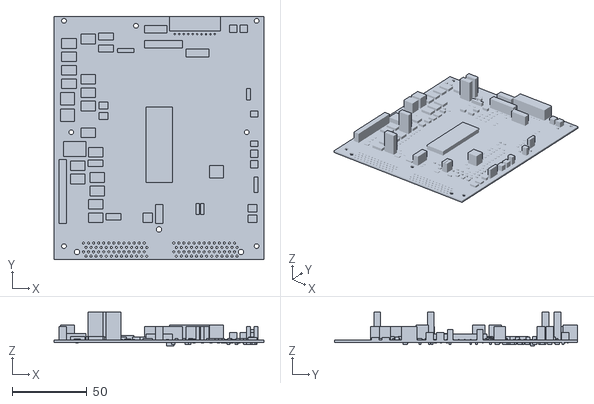
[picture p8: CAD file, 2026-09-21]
mechanical/R10_Component_Envelopes.stl
140.9 x 163.4 x 22.6

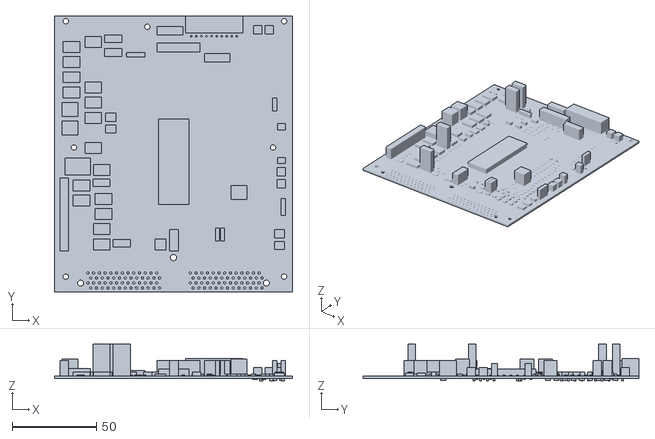
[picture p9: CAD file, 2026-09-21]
mechanical/R7_Component_Envelopes.stl
140.9 x 163.4 x 21.6

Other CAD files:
mechanical/R8_Component_Envelopes.stl

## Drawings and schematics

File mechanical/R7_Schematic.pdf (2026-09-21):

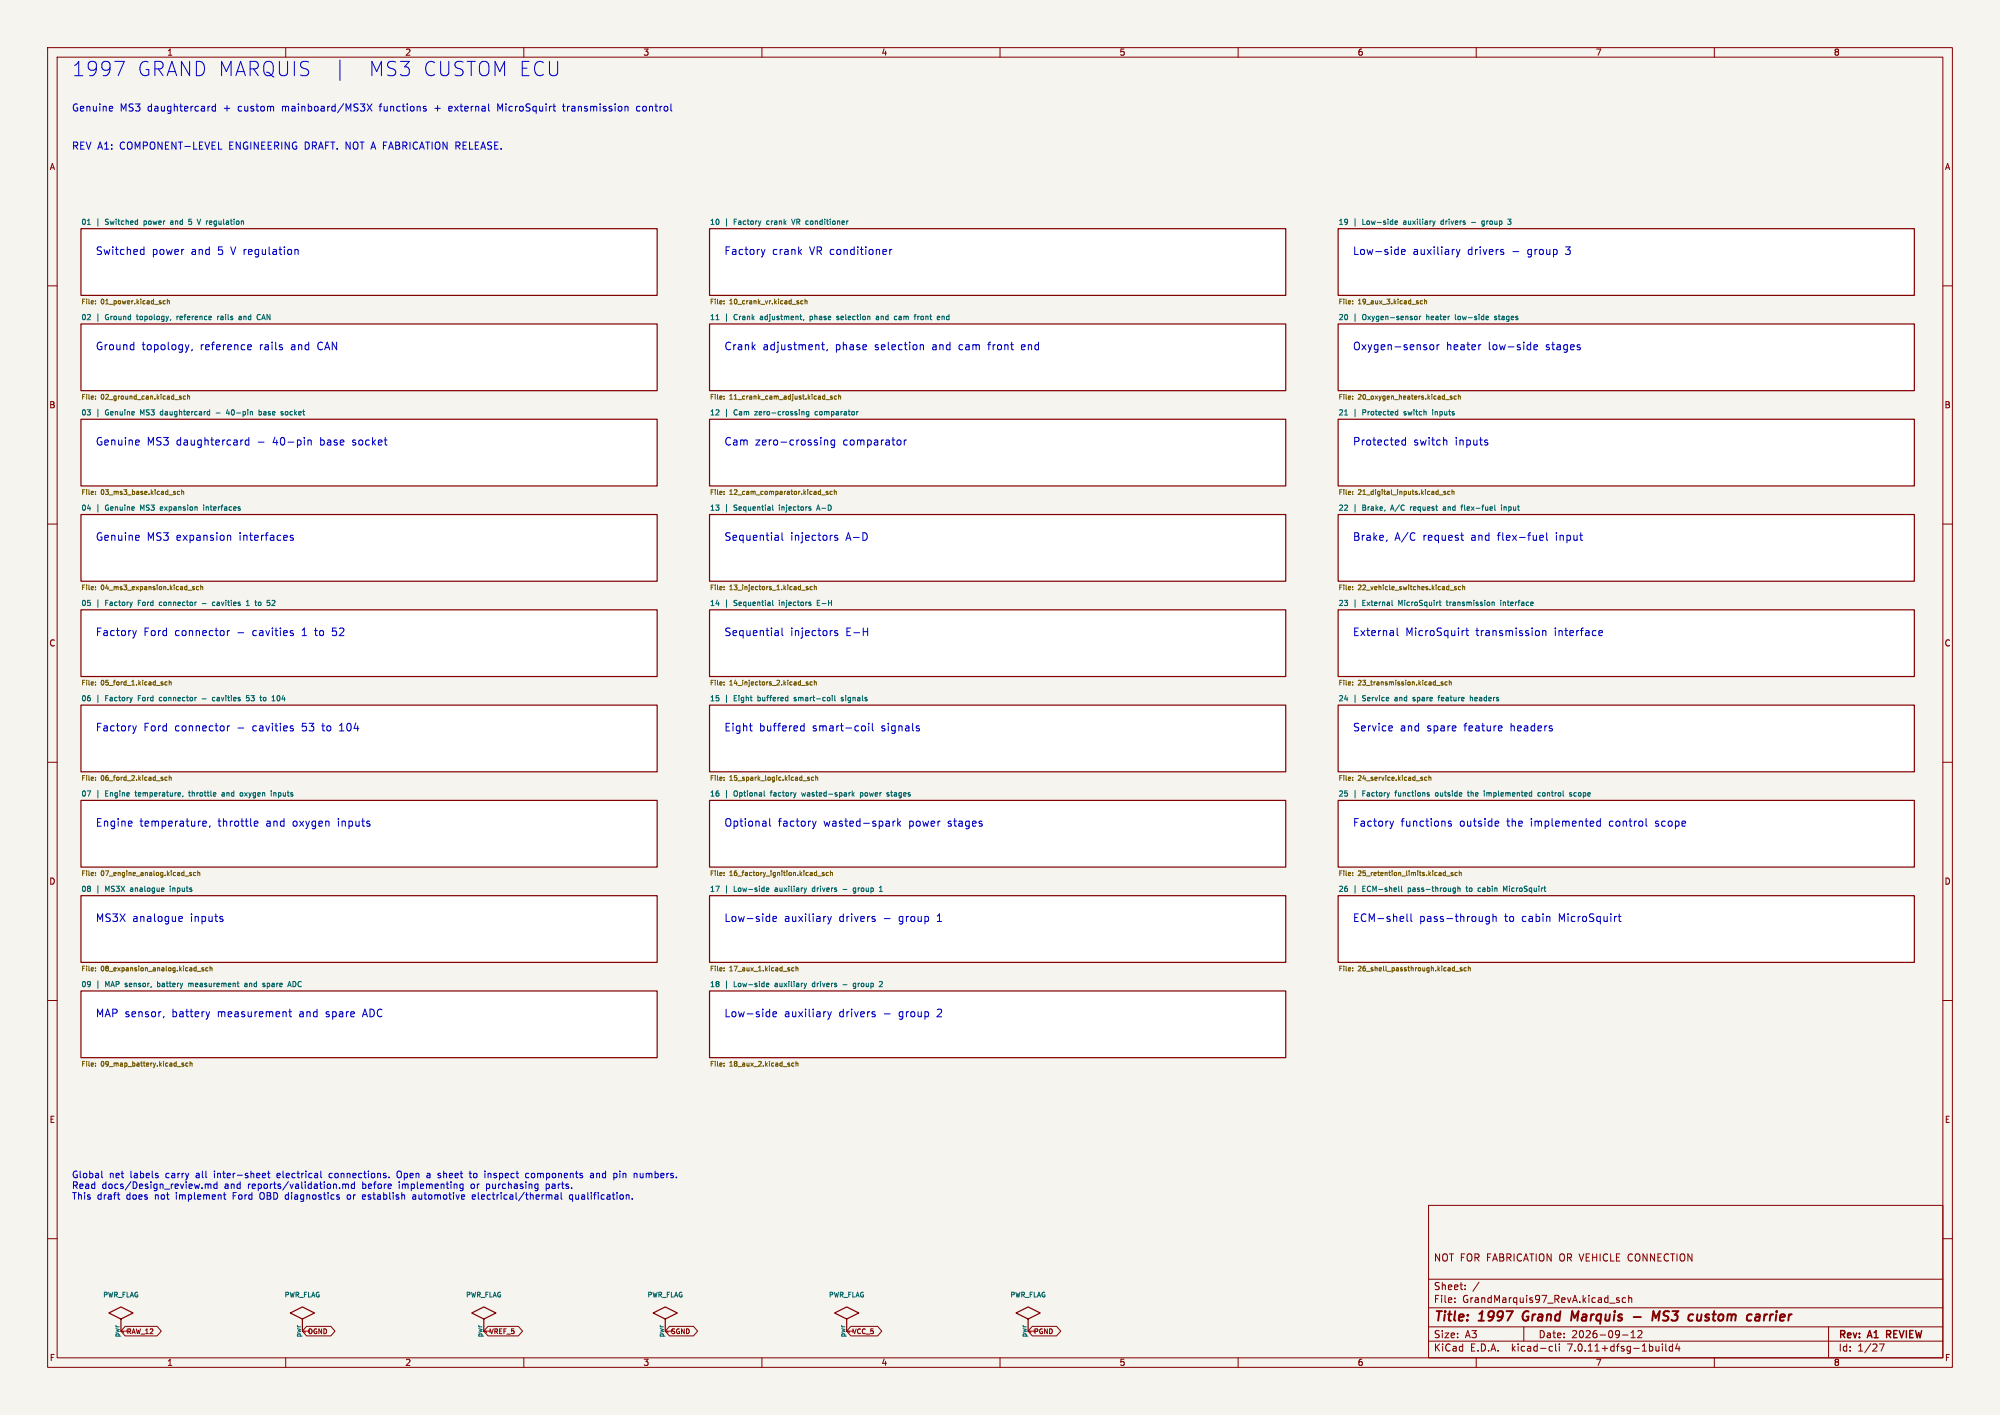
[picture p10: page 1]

REV A1: COMPONENT-LEVEL ENGINEERING DRAFT. NOT A FABRICATION RELEASE.

01 | Switched power and 5 V regulation

Switched power and 5 V regulation

Factory crank VR conditioner

Service and spare feature headers

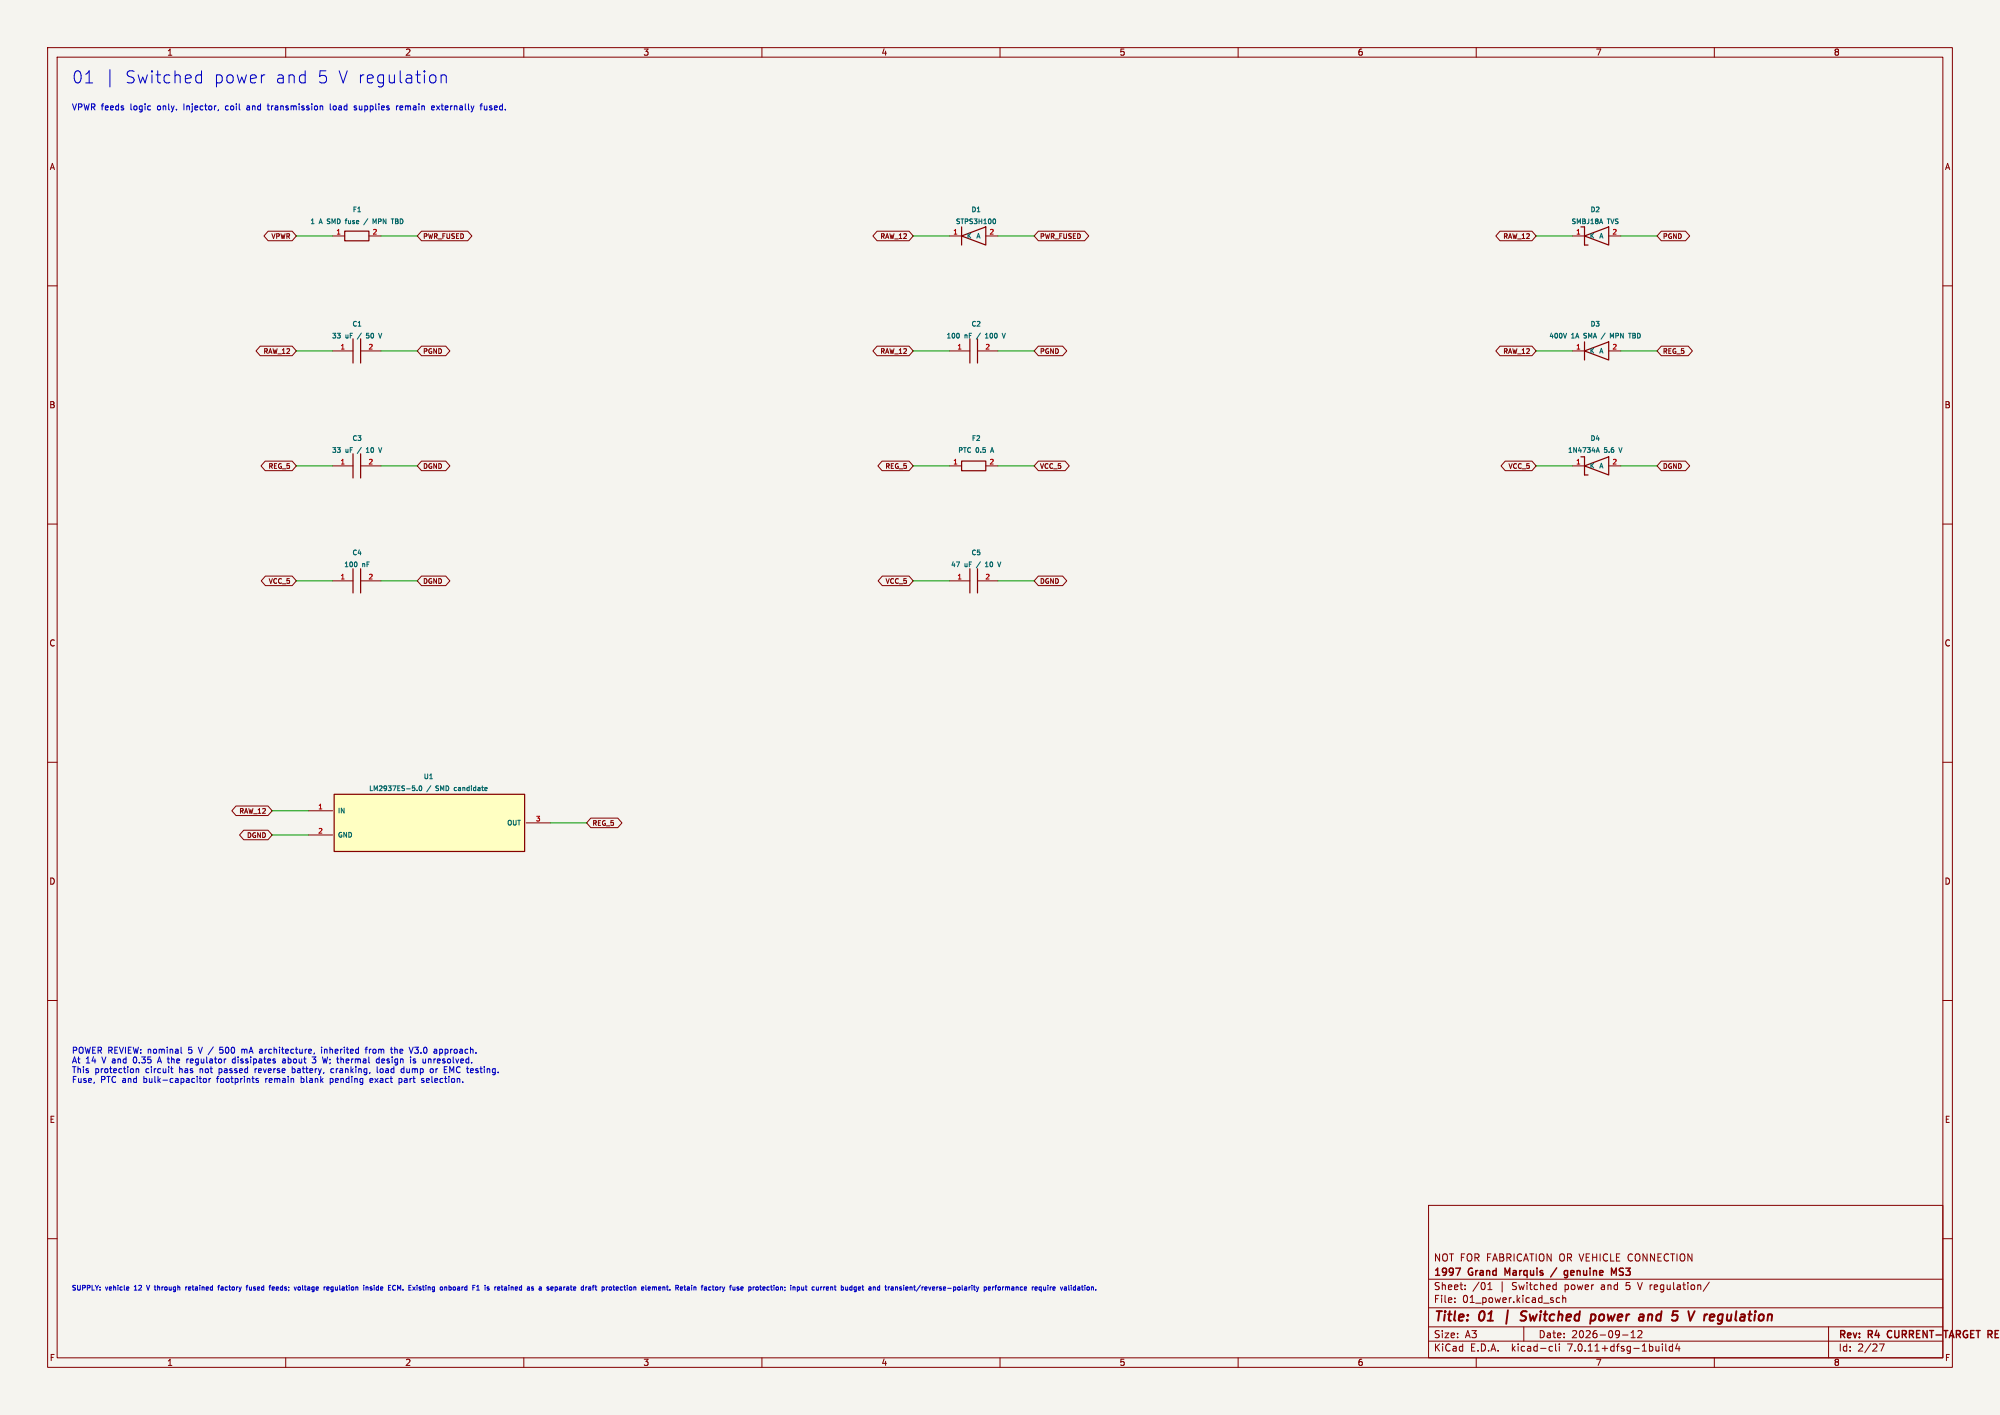
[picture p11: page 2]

01 | Switched power and 5 V regulation

1 A SMD fuse / MPN TBD

Id: 2/27 Title: 01 | Switched power and 5 V regulation

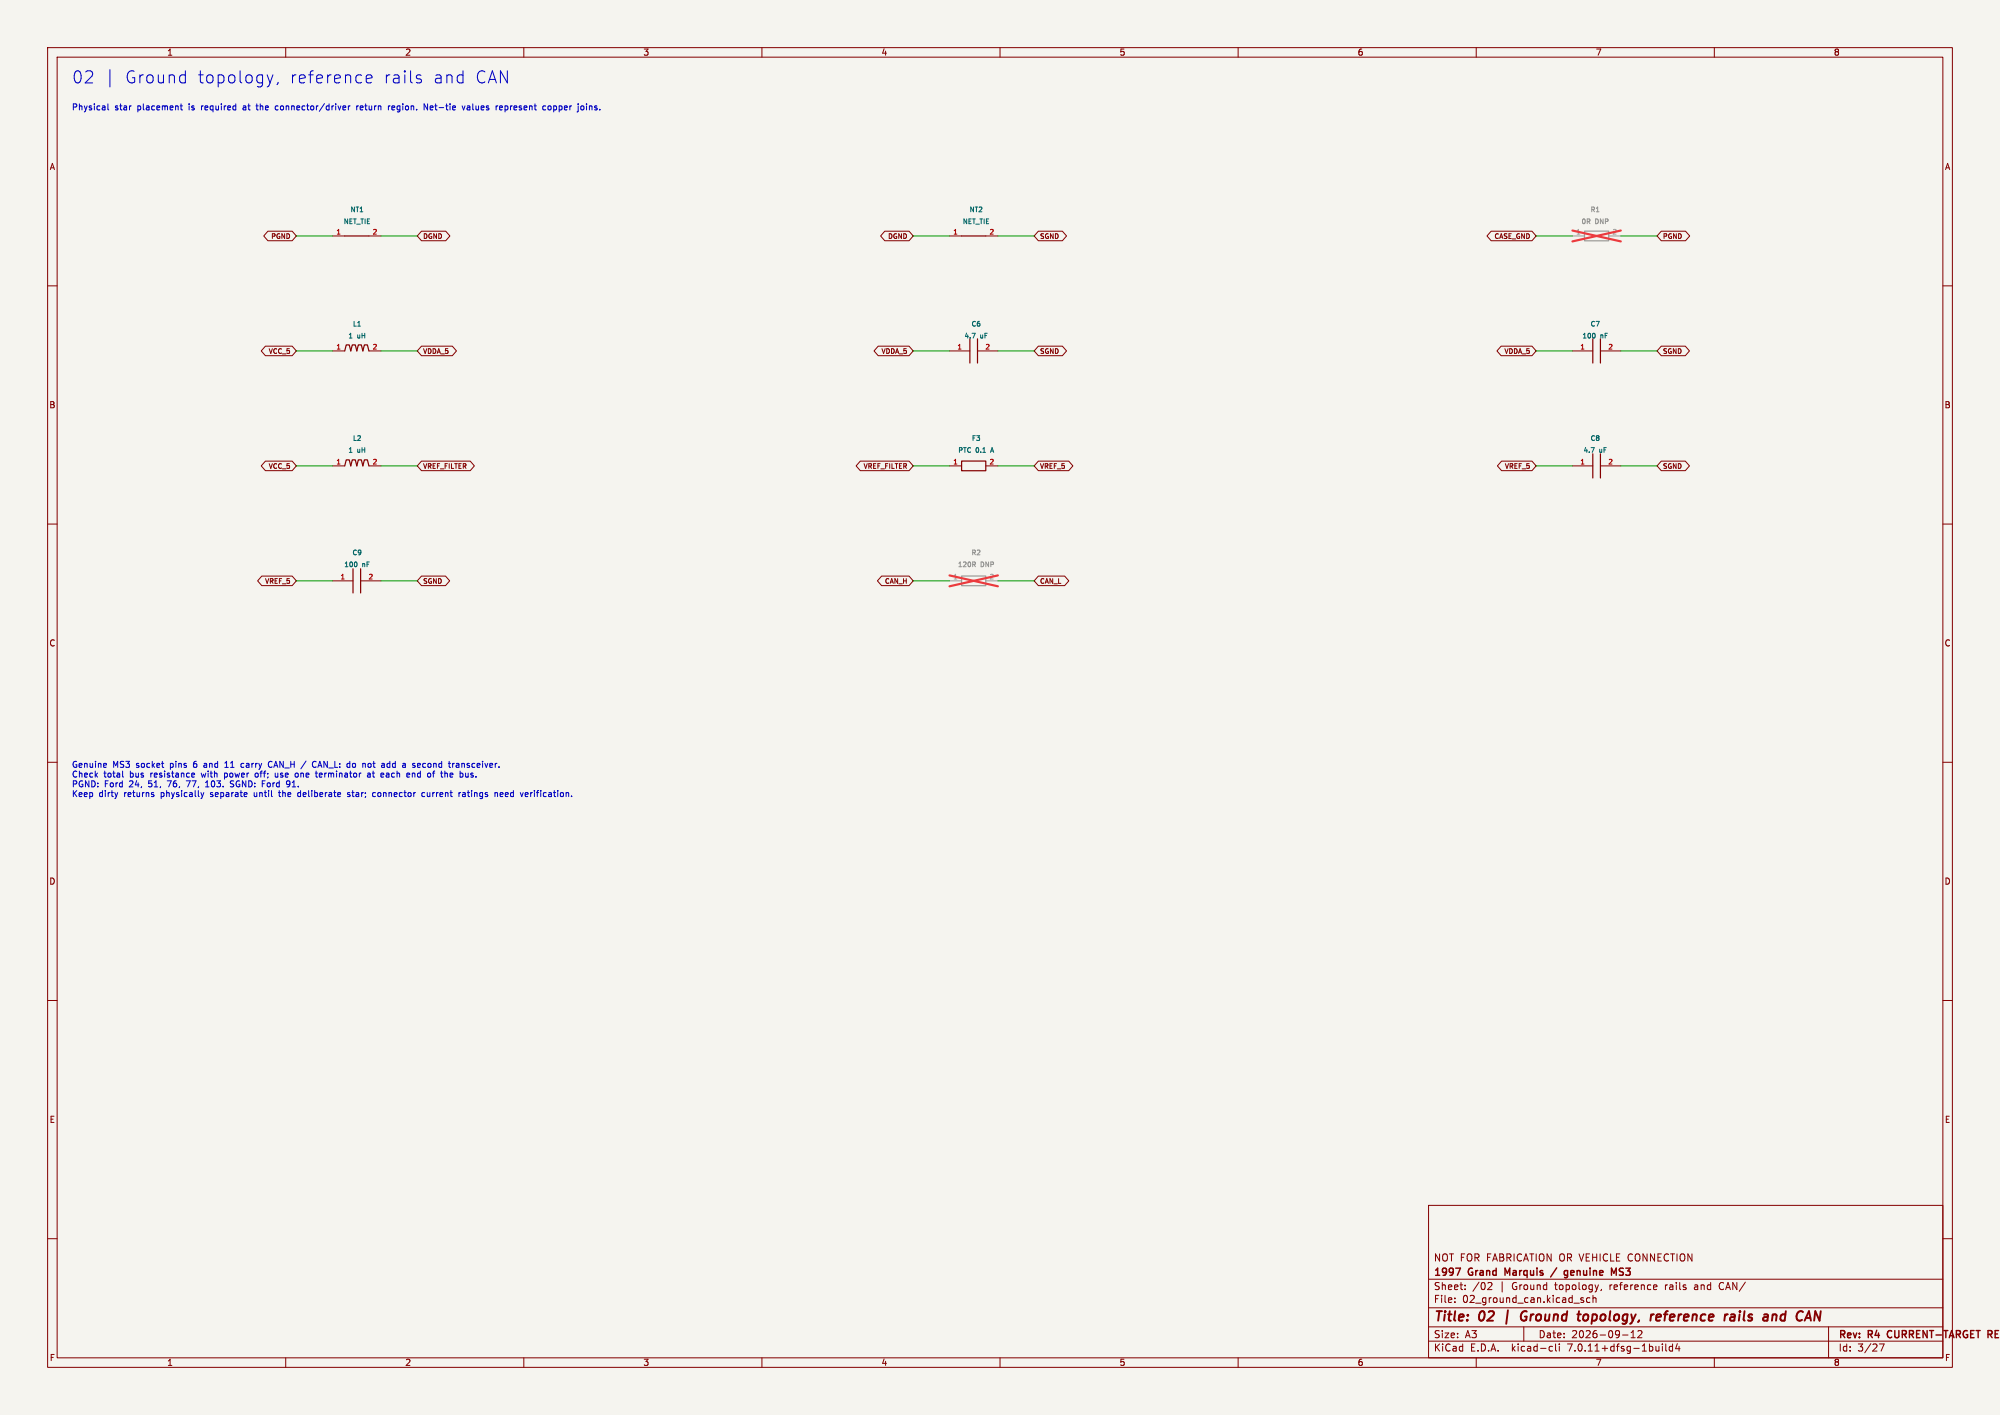
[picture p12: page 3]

02 | Ground topology, reference rails and CAN

Id: 3/27 Title: 02 | Ground topology, reference rails and CAN

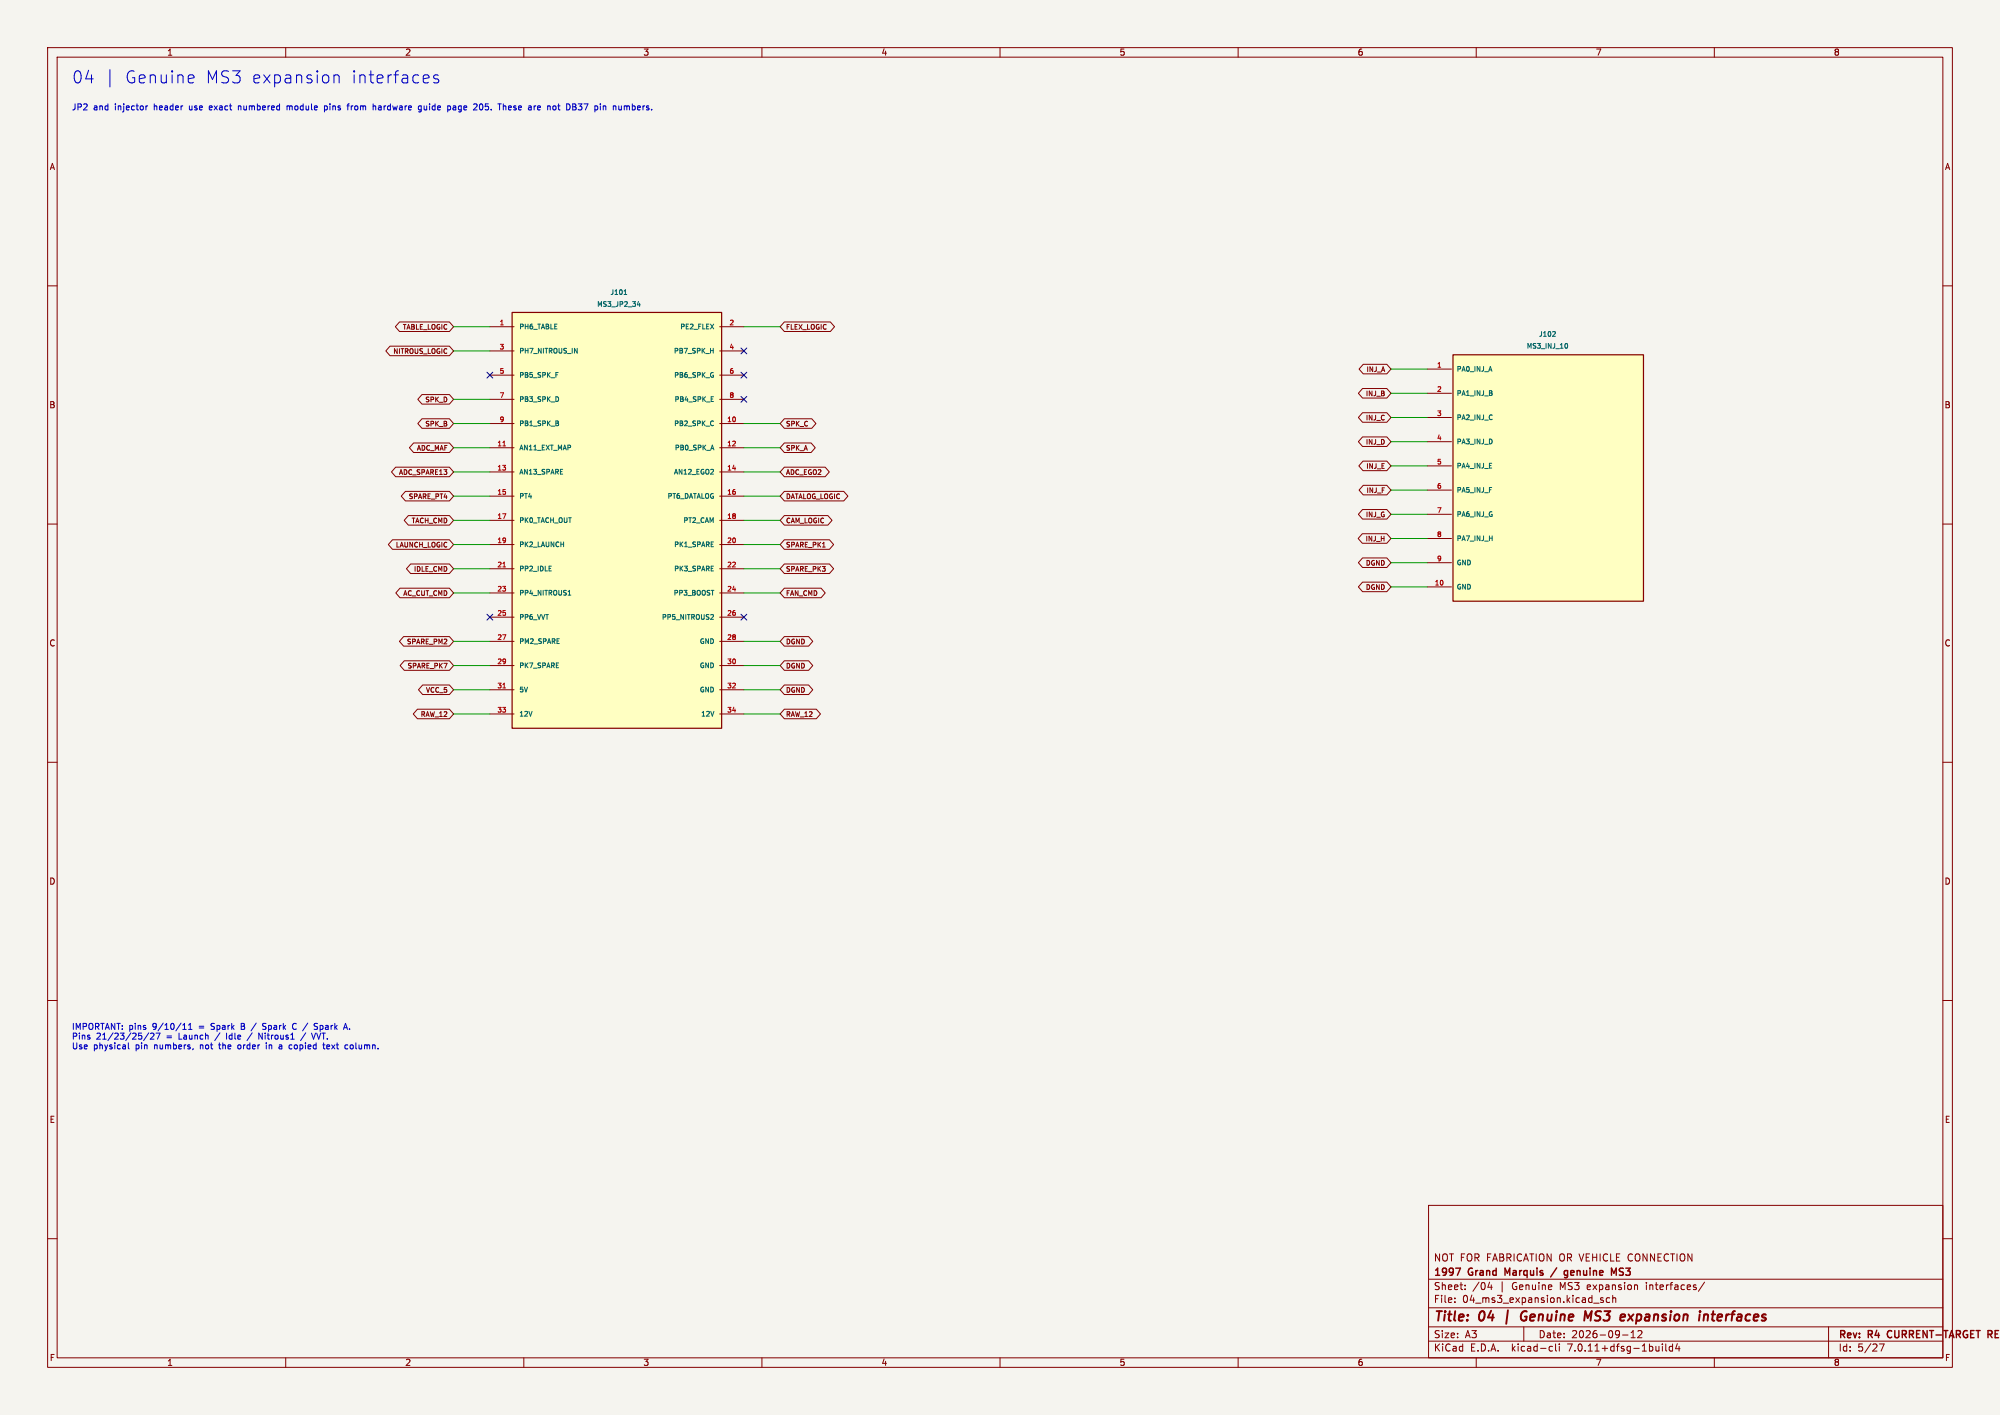
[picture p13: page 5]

Id: 5/27 Title: 04 | Genuine MS3 expansion interfaces

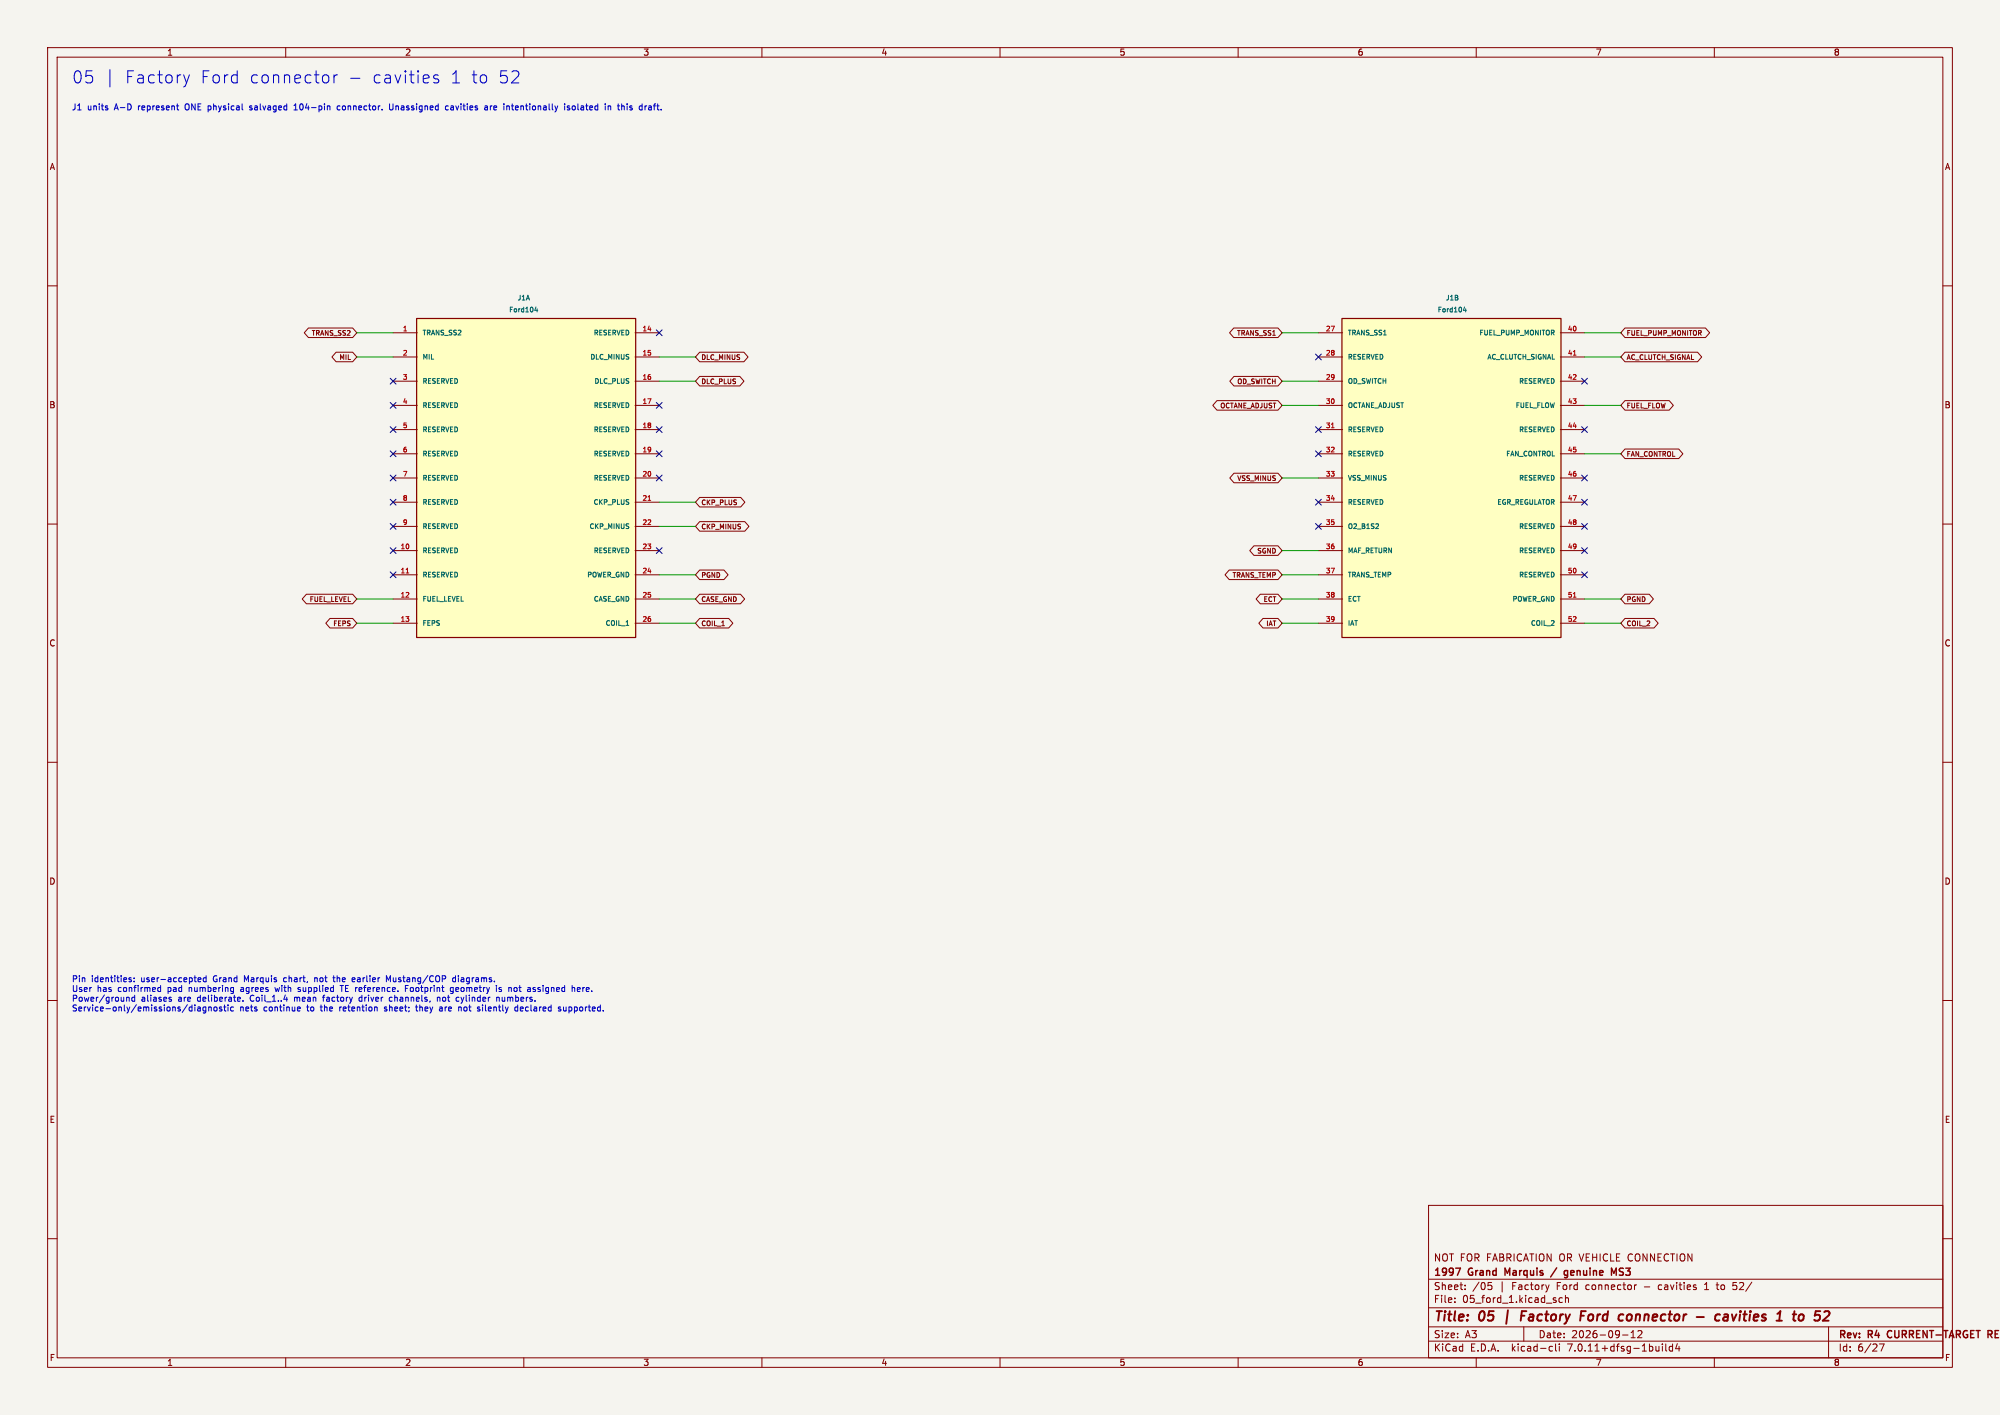
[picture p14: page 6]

Id: 6/27 Title: 05 | Factory Ford connector - cavities 1 to 52

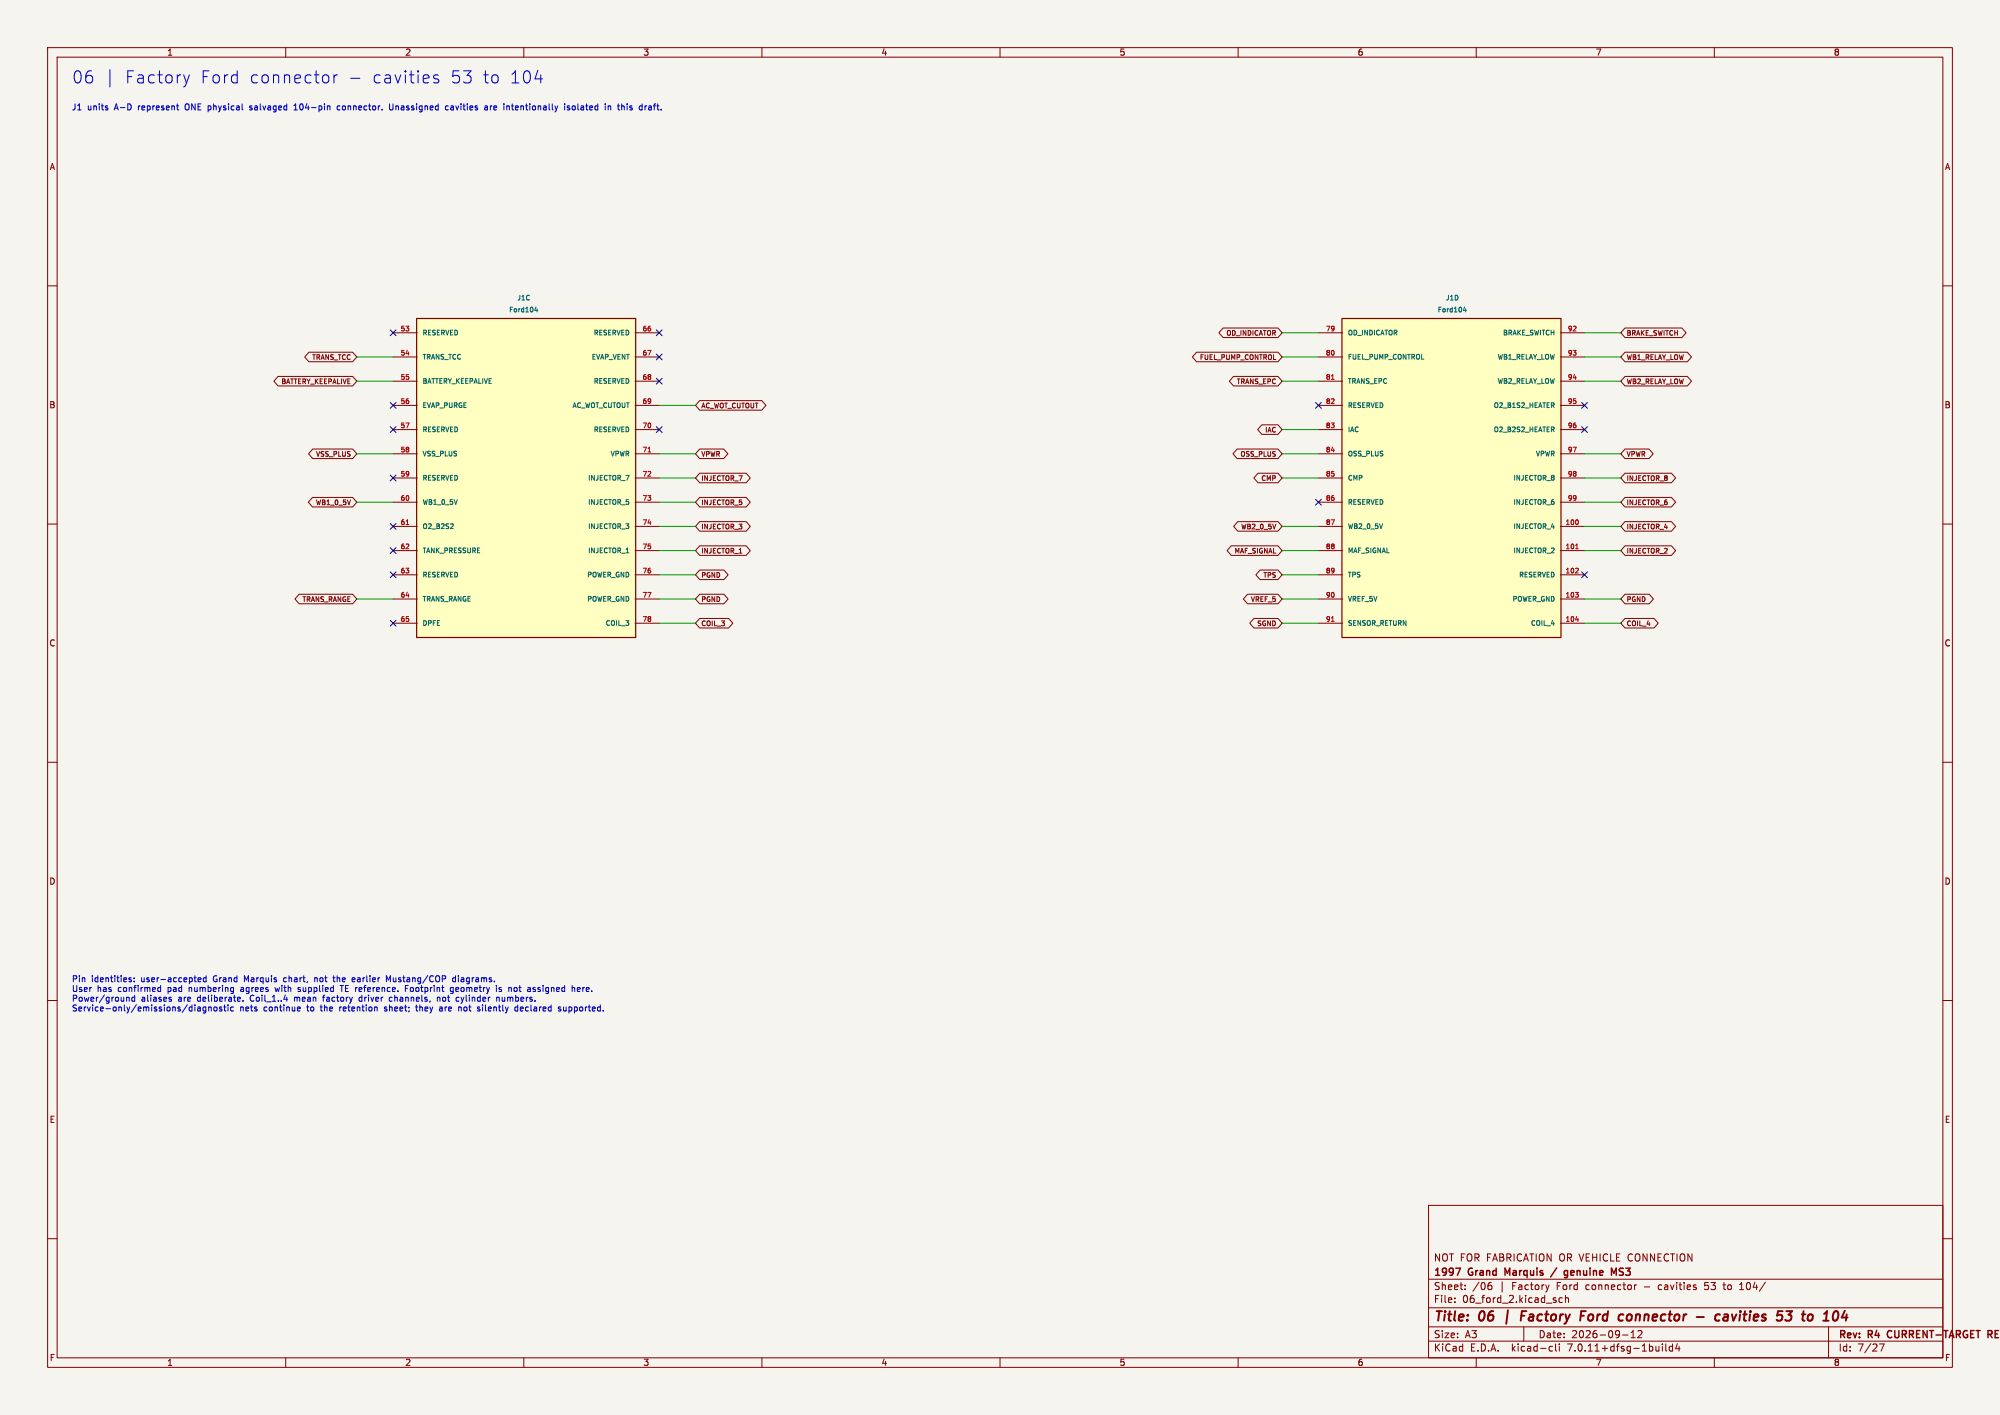
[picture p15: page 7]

Id: 7/27 Title: 06 | Factory Ford connector - cavities 53 to 104

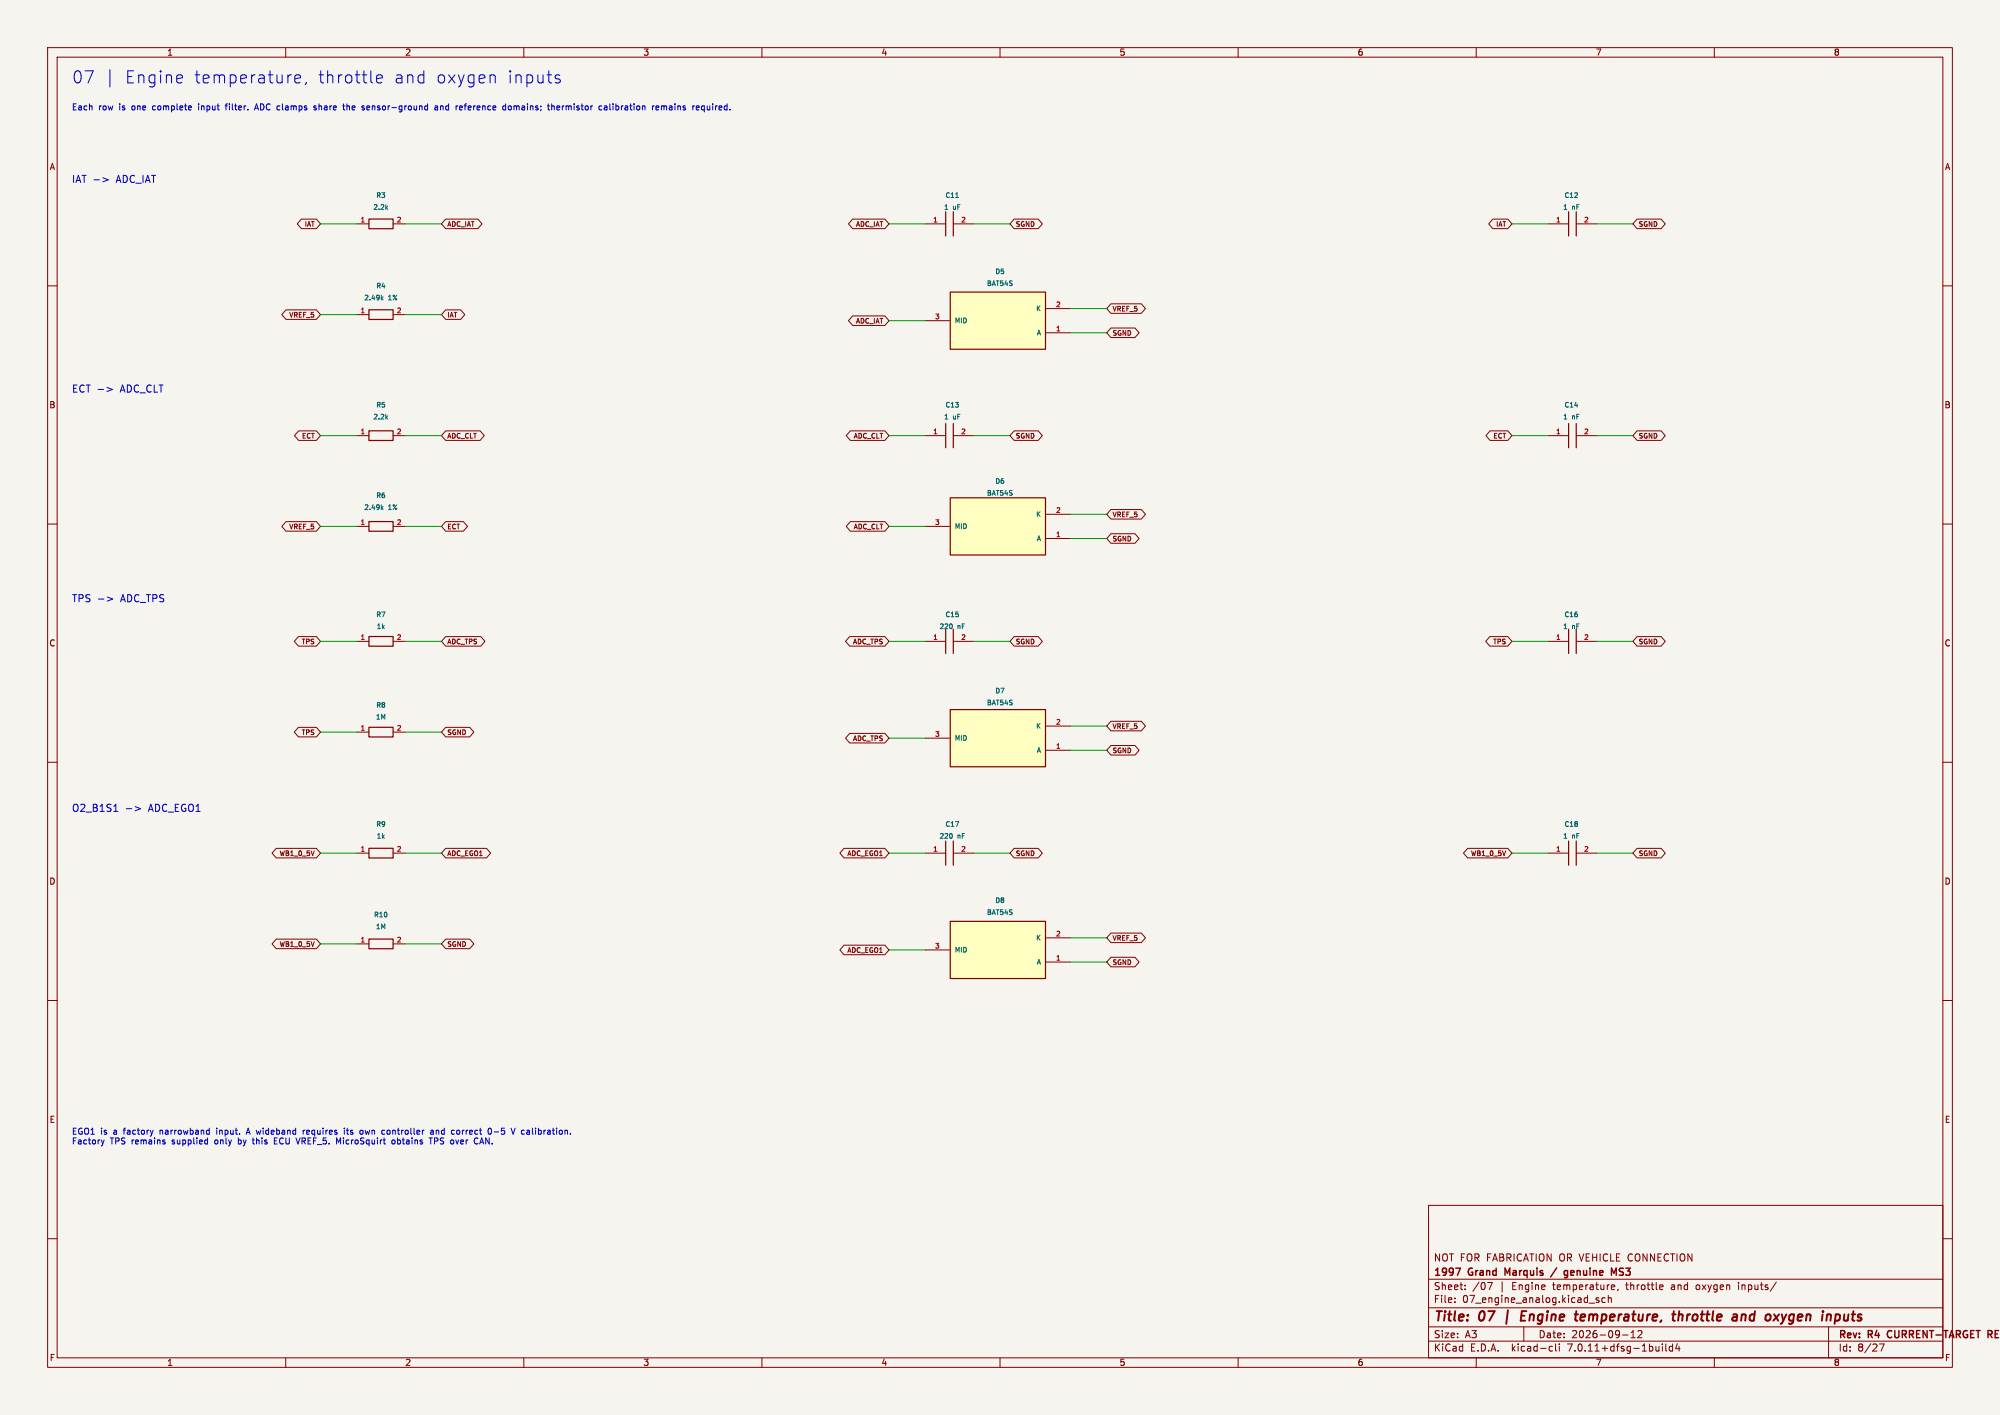
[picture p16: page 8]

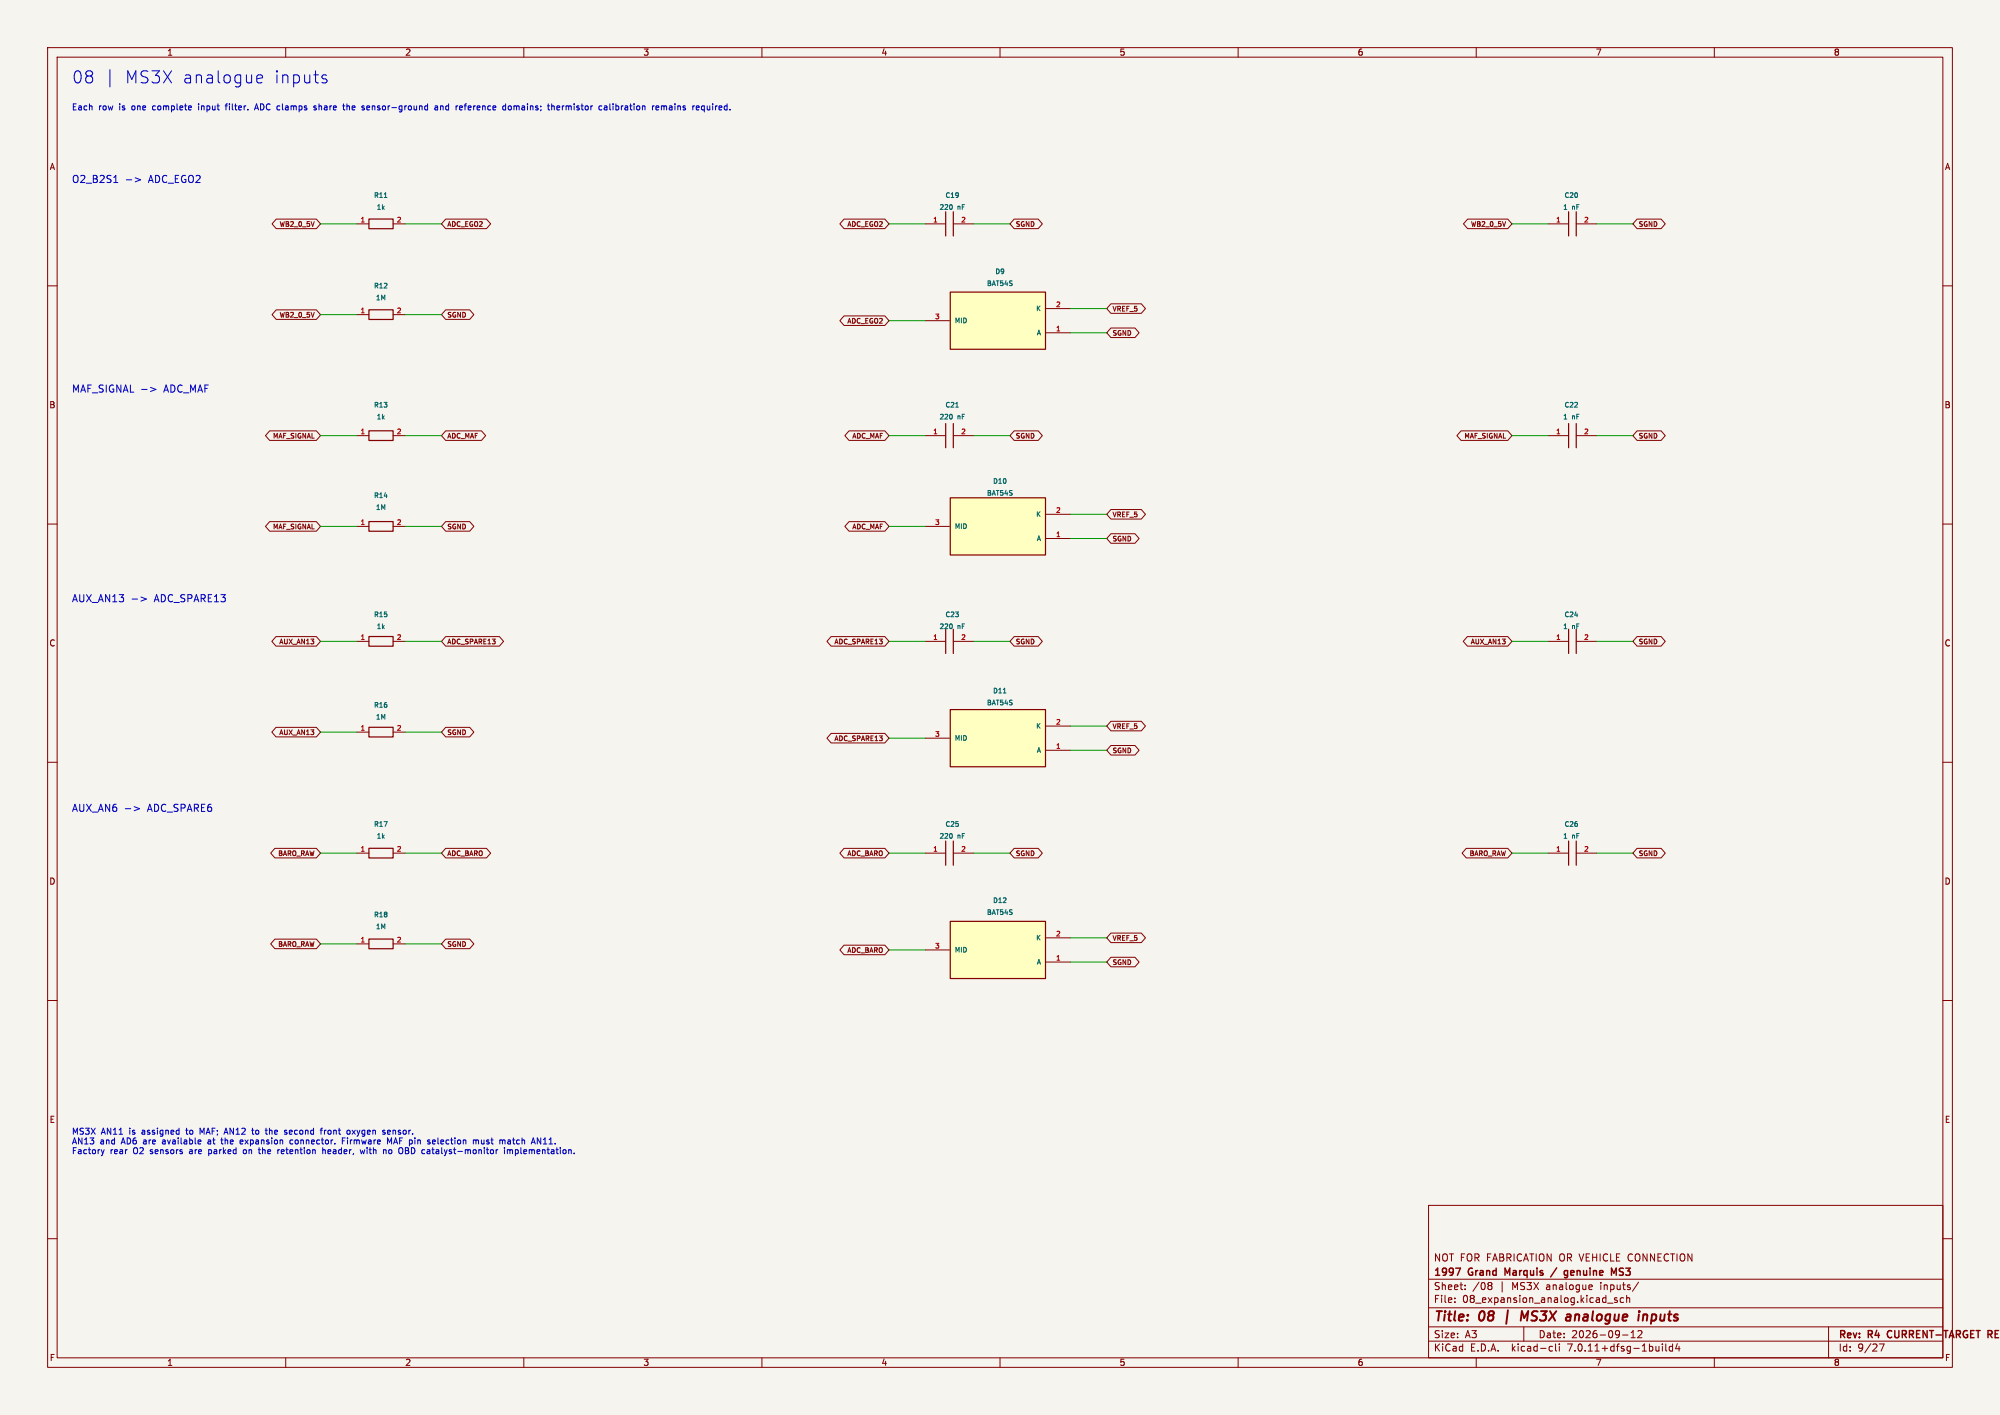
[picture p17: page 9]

Id: 9/27 Title: 08 | MS3X analogue inputs

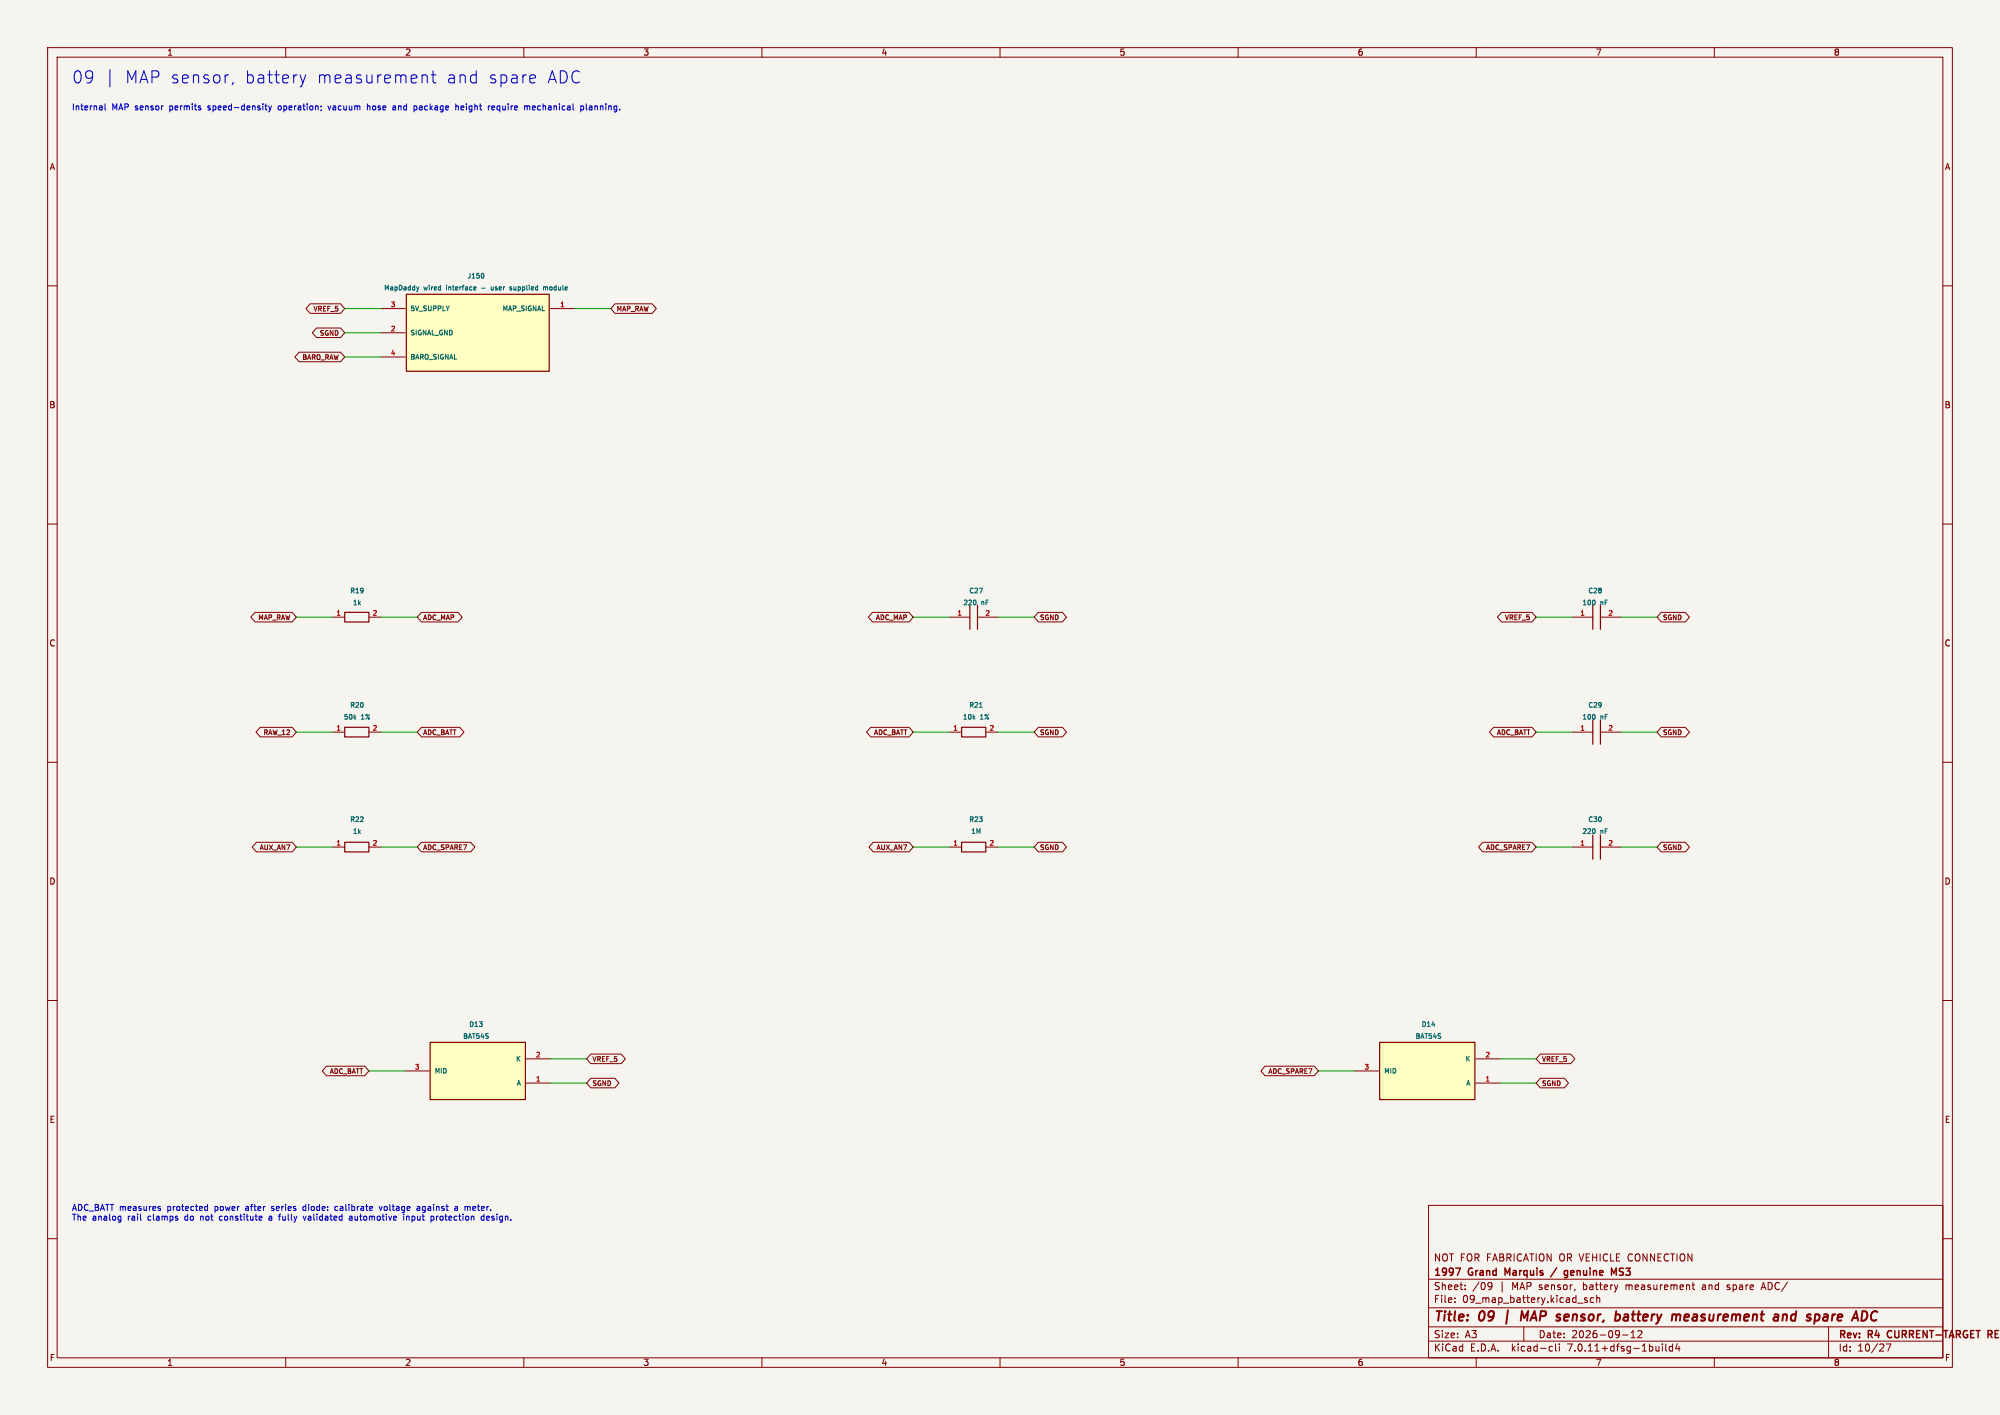
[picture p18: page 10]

Id: 10/27 Title: 09 | MAP sensor, battery measurement and spare ADC

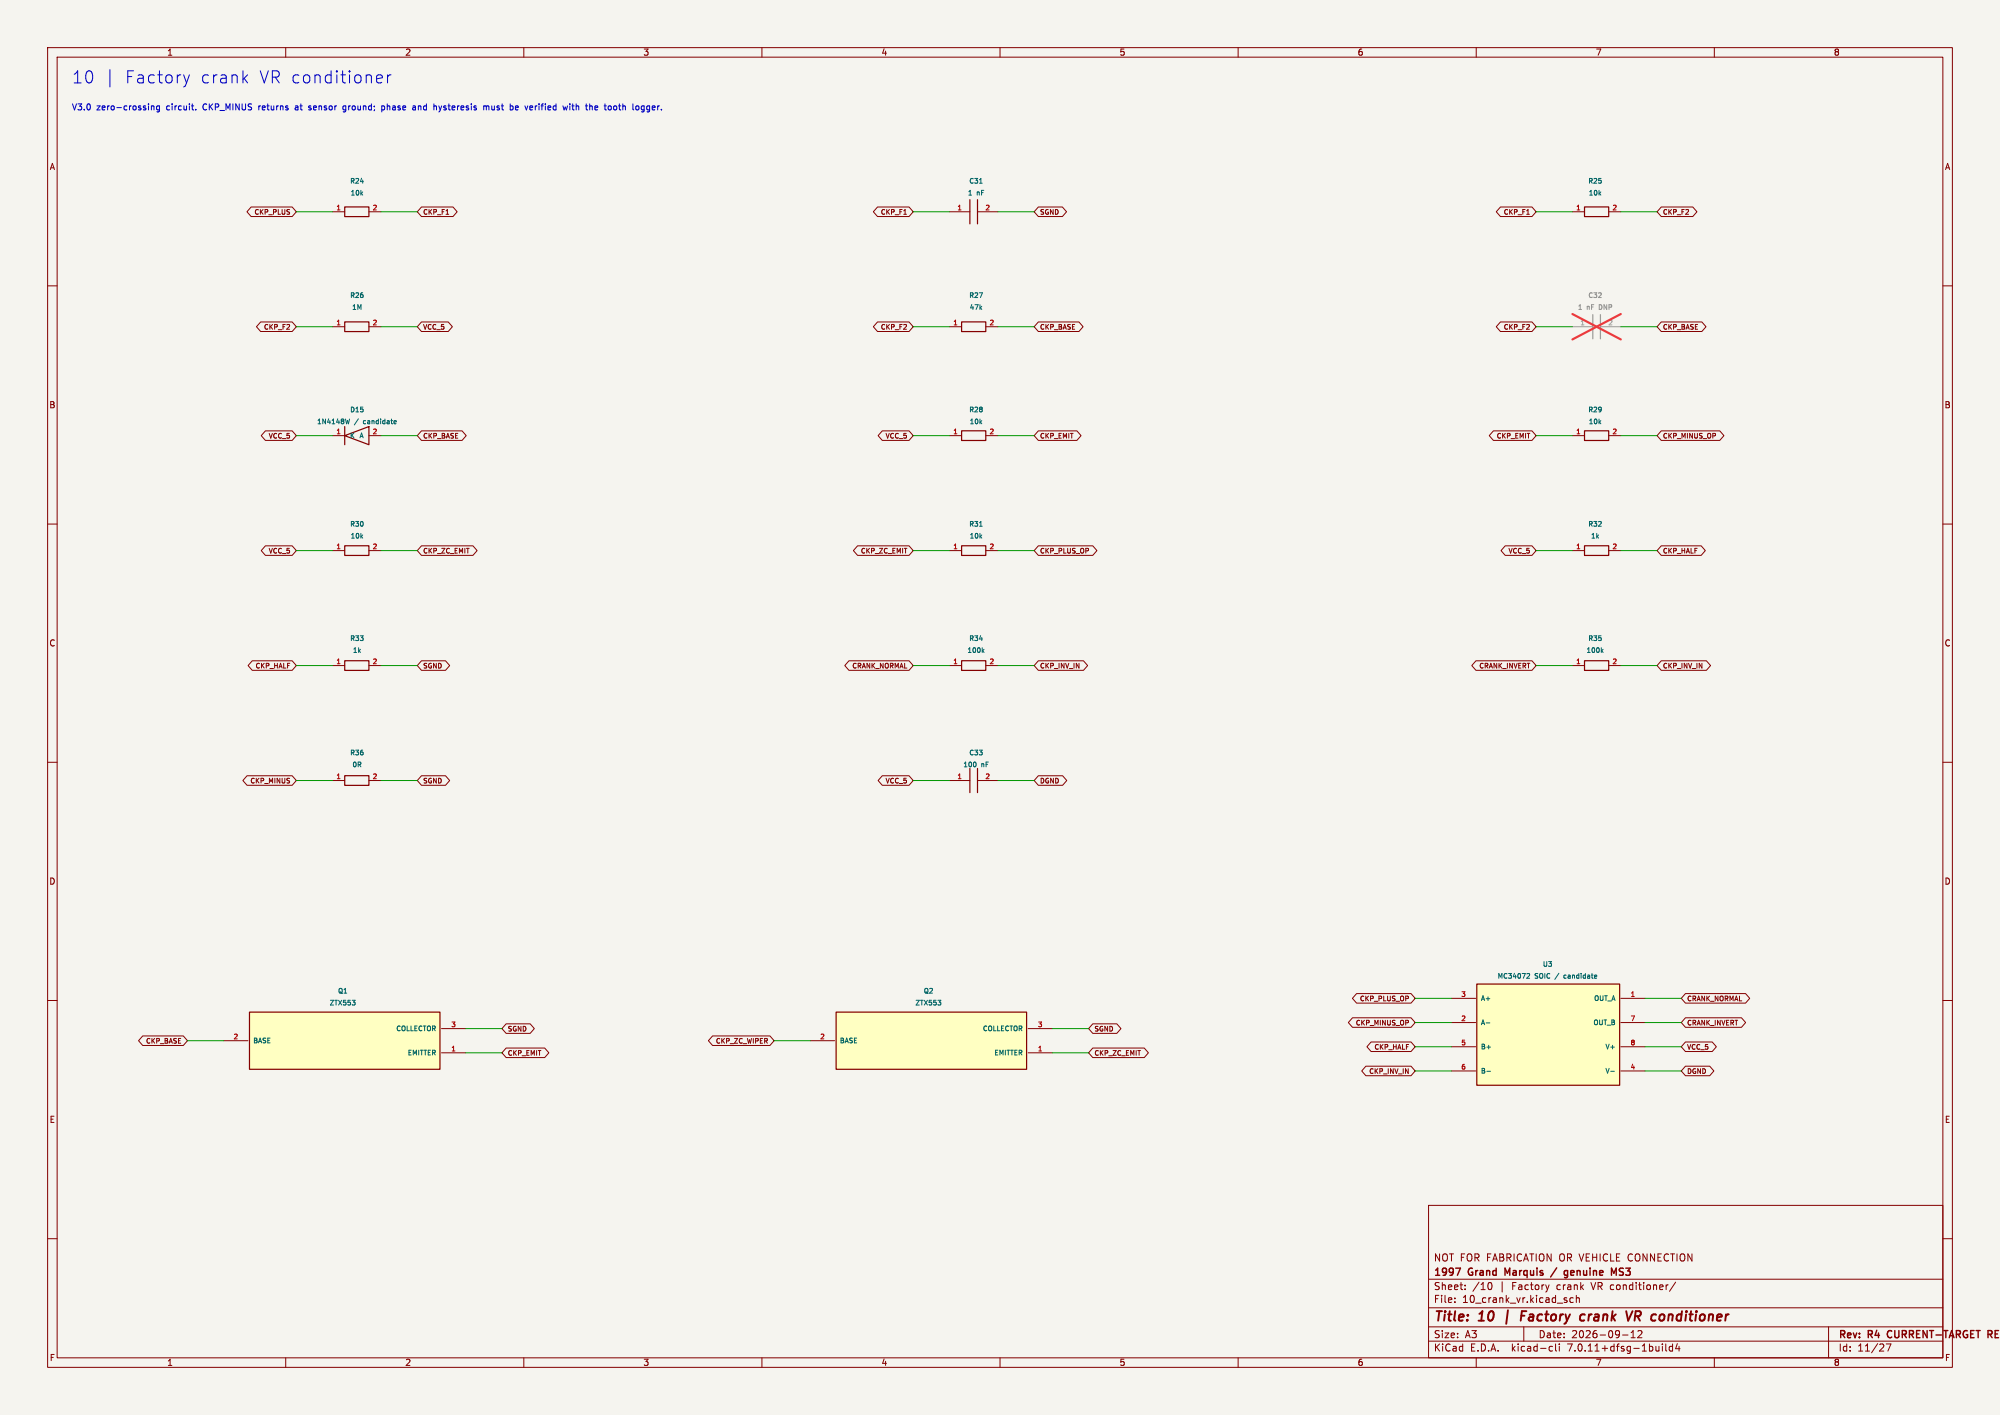
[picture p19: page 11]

10 | Factory crank VR conditioner

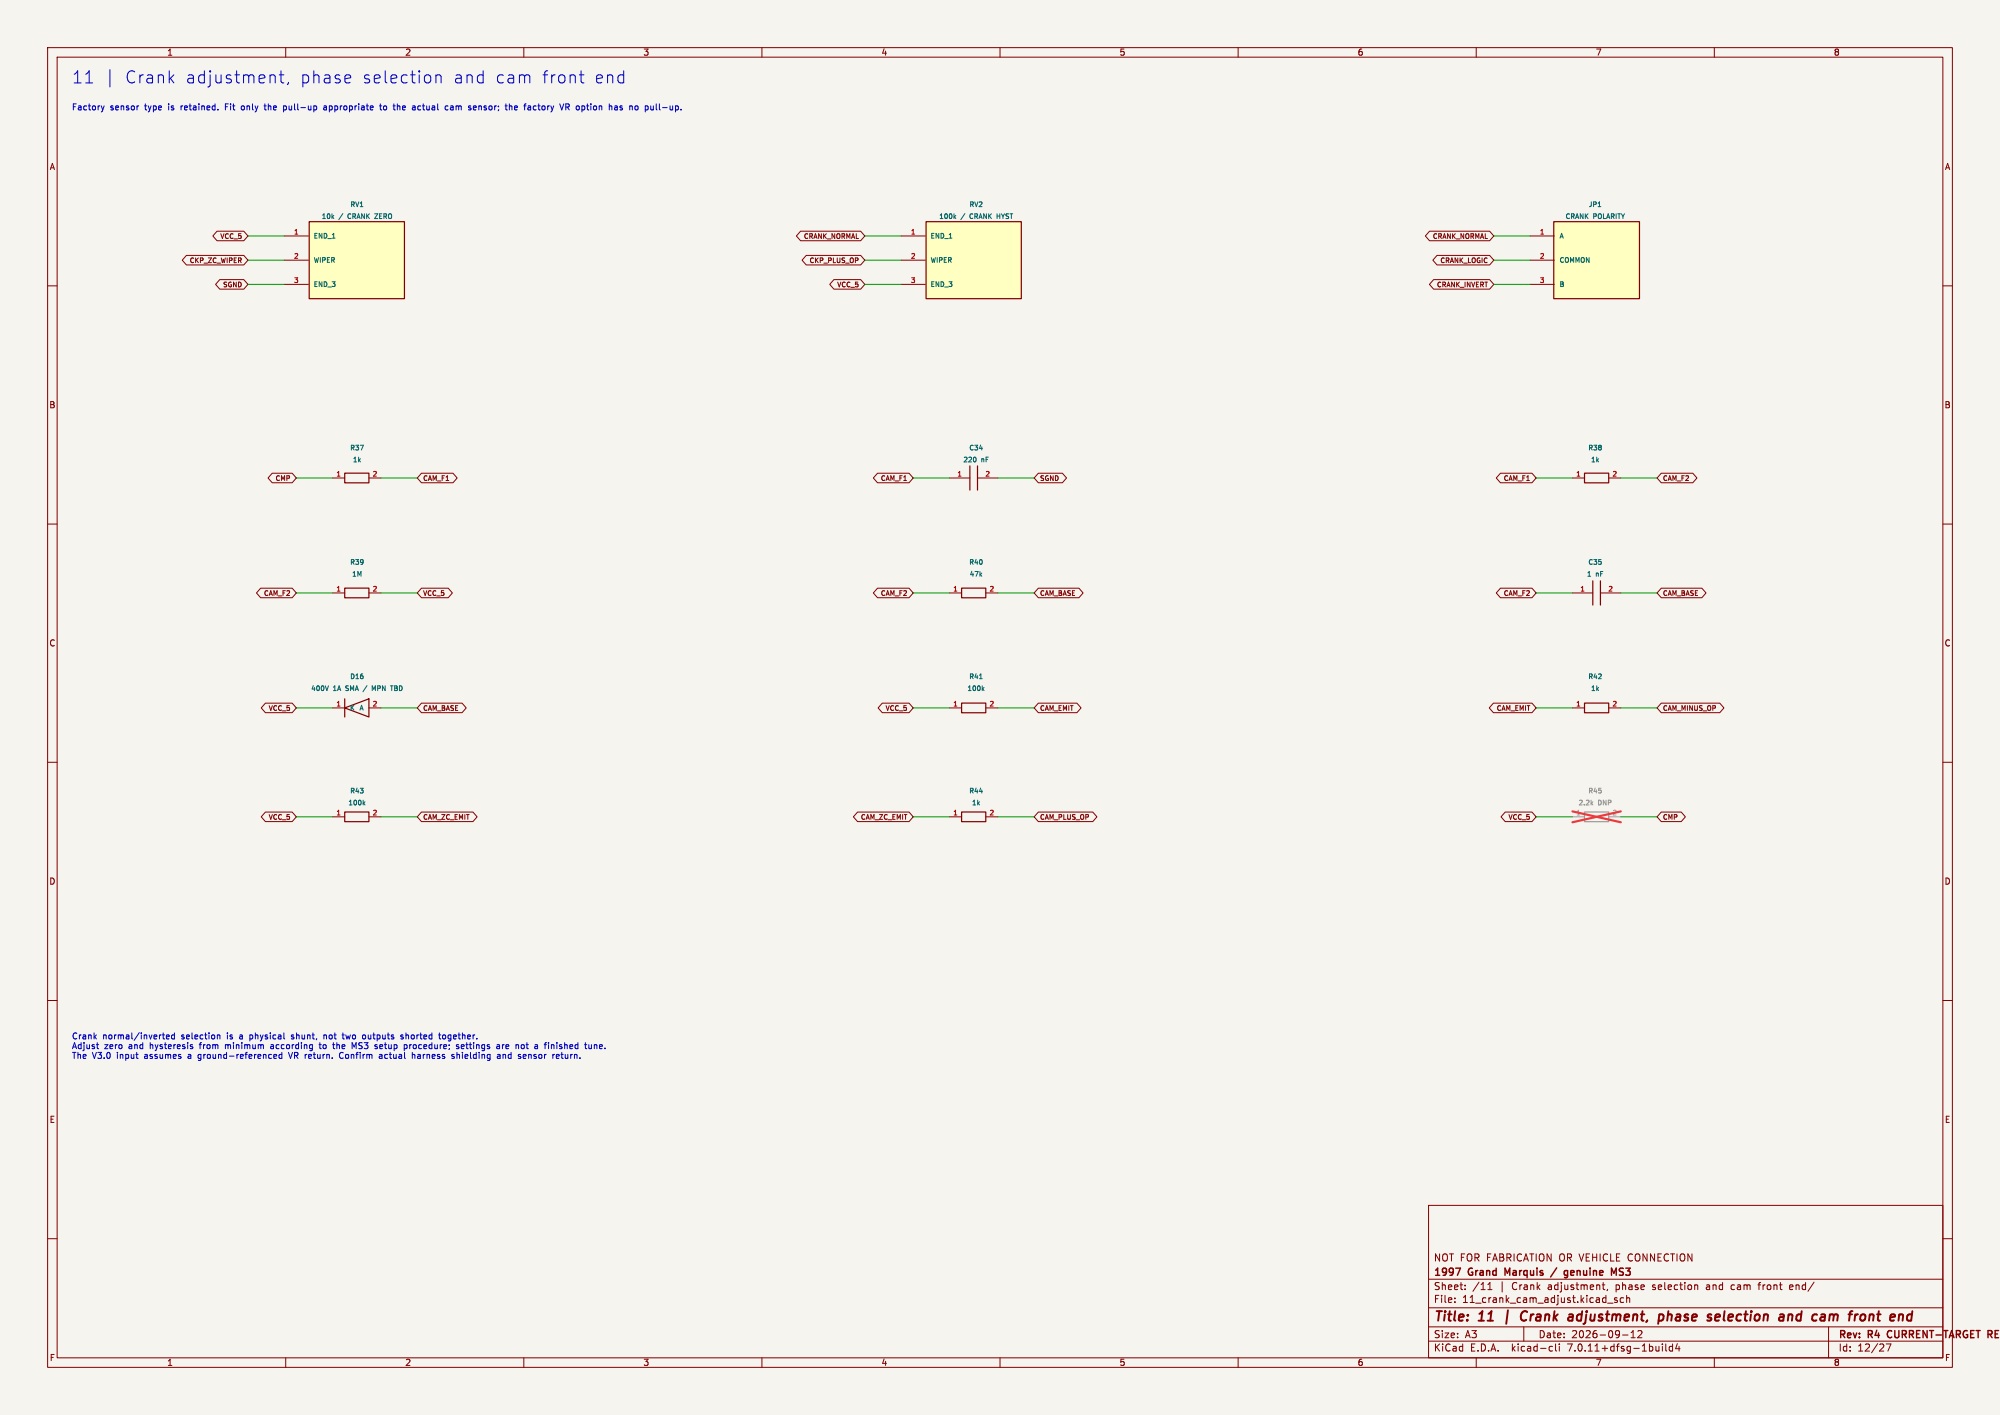
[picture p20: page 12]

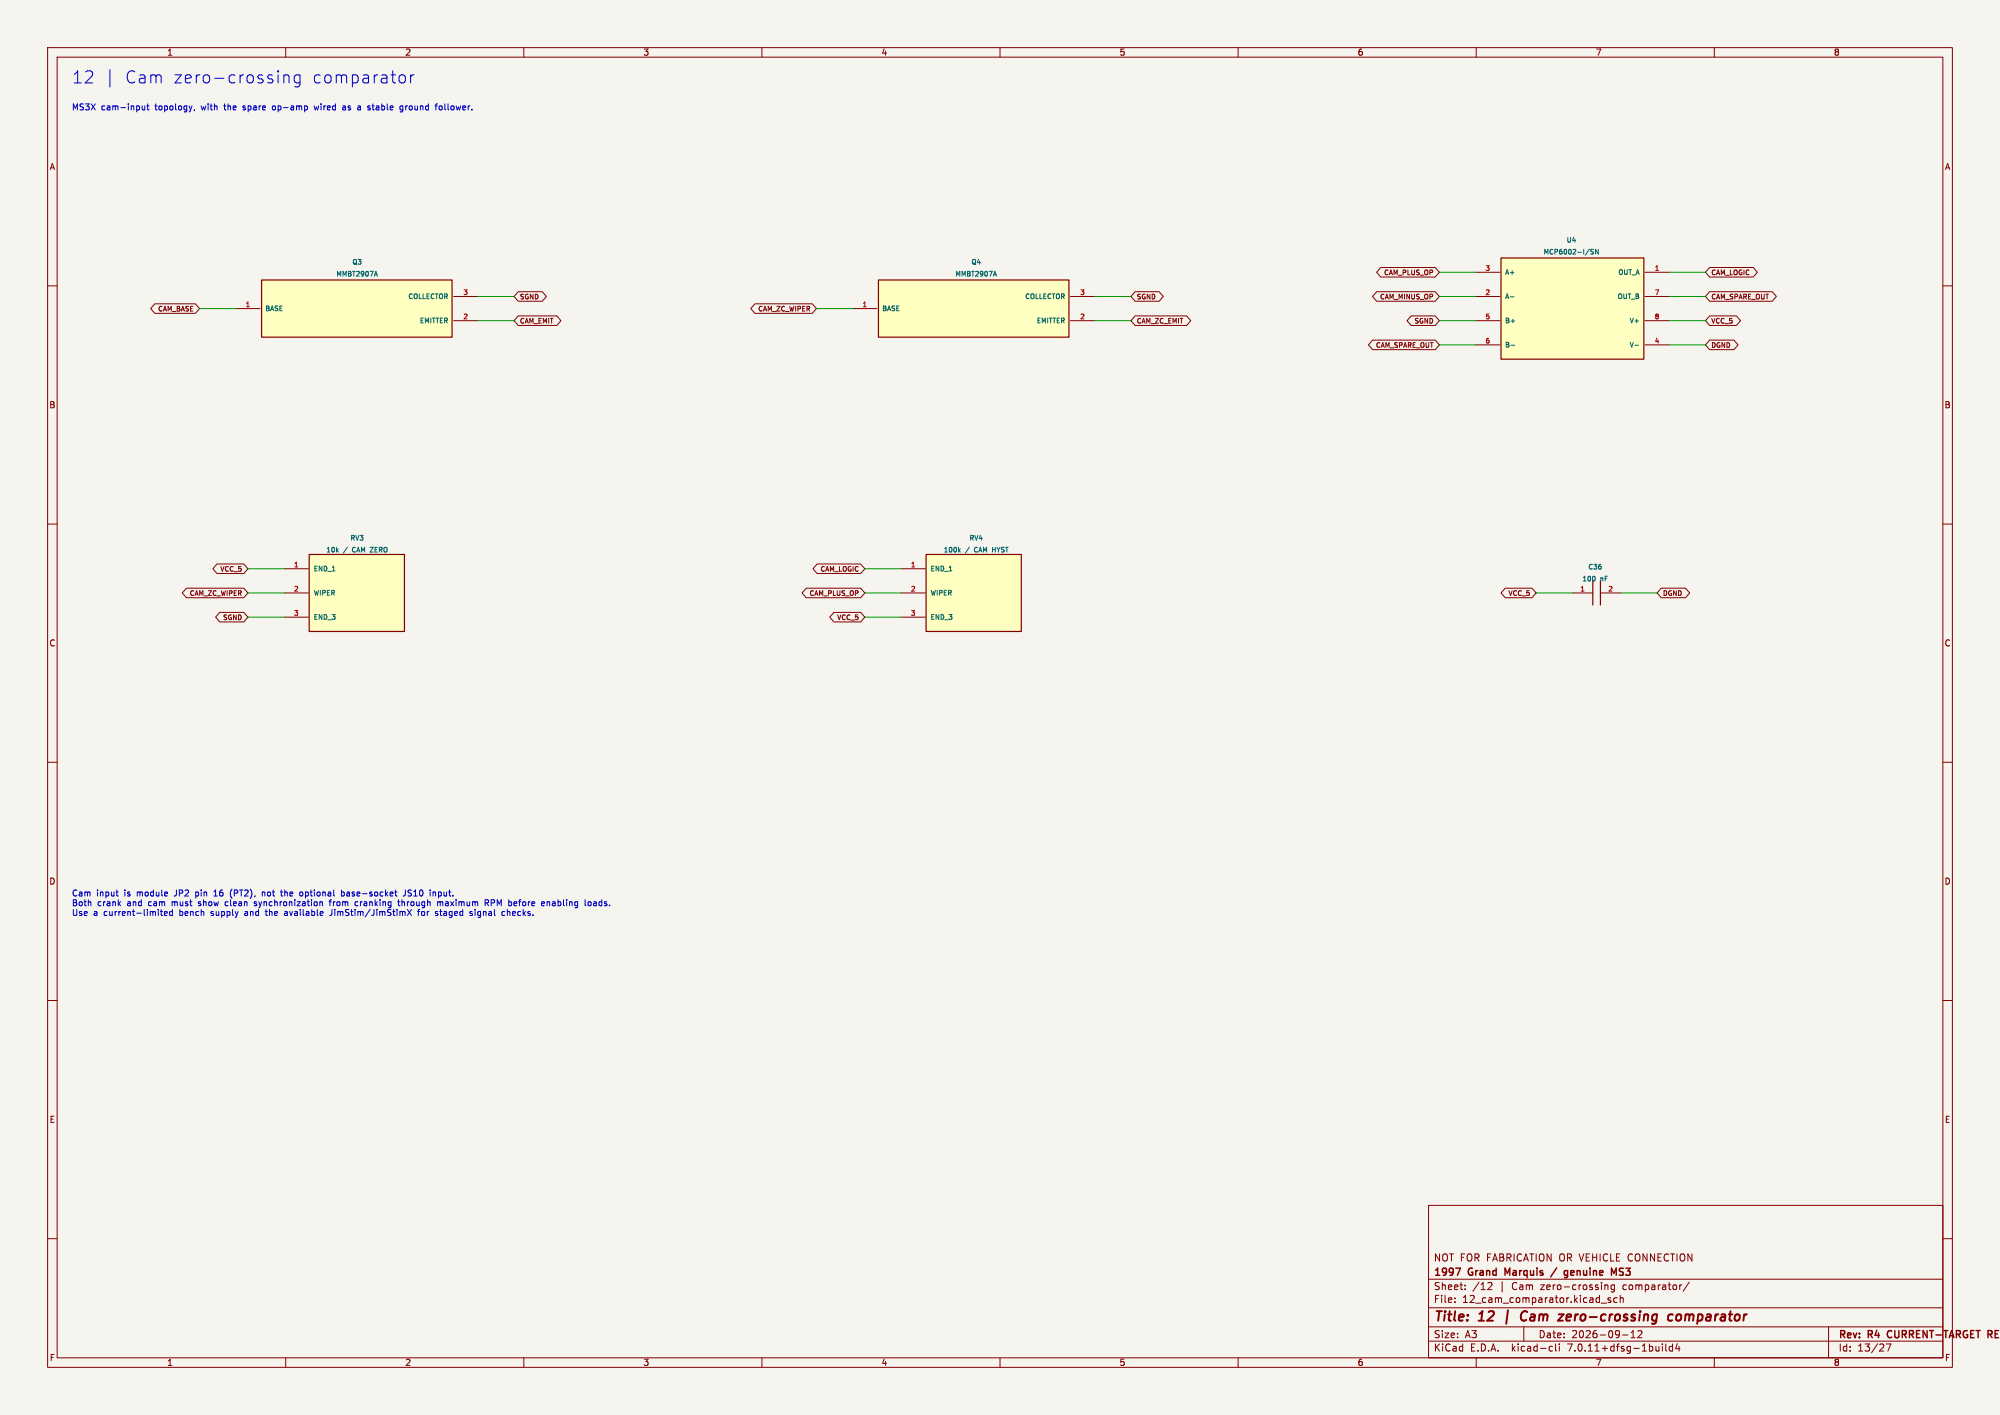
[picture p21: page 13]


Id: 14/27 Title: 13 | Sequential injectors A-D


Id: 15/27 Title: 14 | Sequential injectors E-H





FUEL_PUMP_CONTROL | Fuel pump RELAY only



Id: 22/27 Title: 21 | Protected switch inputs



Id: 25/27 Title: 24 | Service and spare feature headers


Id: 26/27 Title: 25 | Factory functions outside the implemented control scope


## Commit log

2026-09-21 Initial Commit
    Initial Commit
    [01_power.kicad_sch, 02_ground_can.kicad_sch, 03_ms3_base.kicad_sch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]
2026-09-21 Add reproducible R10 baseline audit
    [LOCKED_COPPER_AUDIT.csv]
